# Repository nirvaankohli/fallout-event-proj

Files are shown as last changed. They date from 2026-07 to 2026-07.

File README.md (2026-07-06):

# FALL-E

<replace>with pic of the zine</replace>

---

# The Problem

So the world is ending on the 7th of July, and the human species may not survive. Soup, however, can survive the incoming apocalypse, but only with help. Soup needs a companion to accompany itself(as soup can't walk) to preserve the legacy of humankind for the next species to rule Earth.

---

# What is FALL-E?

FALL-E is a robot inspired by the Pixar movie "WALL-E" and is meant to preserve soup and the legacy of the human species after the destruction of the world. It has a tank-drive chassis with two independent tracks(motor on each side).

FALL-E features a Seeed Studio XIAO ESP32C3, 2 DC Motors, and a DRV8833 Motor Driver. 

---

# Why choose FALL-E?

Our team went into this competition wanting to create something to protect soup and preserve humankind's legacy. We started brainstorming ideas that could do that. Ultimately, two avenues presented themselves: one giving soup weaponry (like a turret) or giving it a form of transportation. We ultimately settled on a robot to keep soup company, provide protection, and a form of transportation. We wanted to base it off of WALL-E because it too was exploring a barren, destroyed Earth.

---

# Zine
 Zine (8)

---

## Bill of materials

- BOM: [bom.csv](bom.csv)

---

# IRL Pics

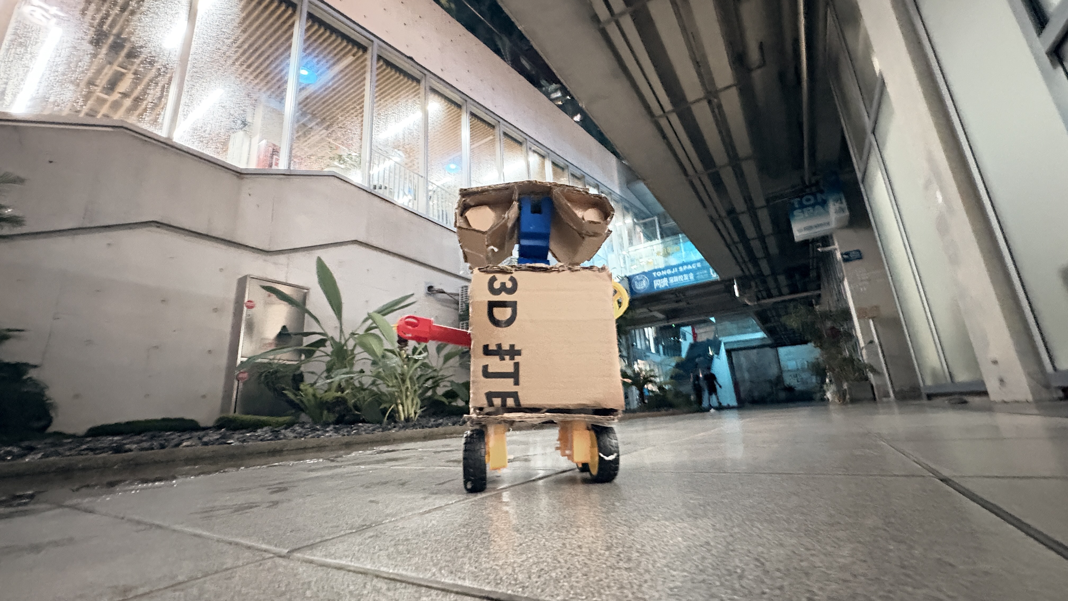
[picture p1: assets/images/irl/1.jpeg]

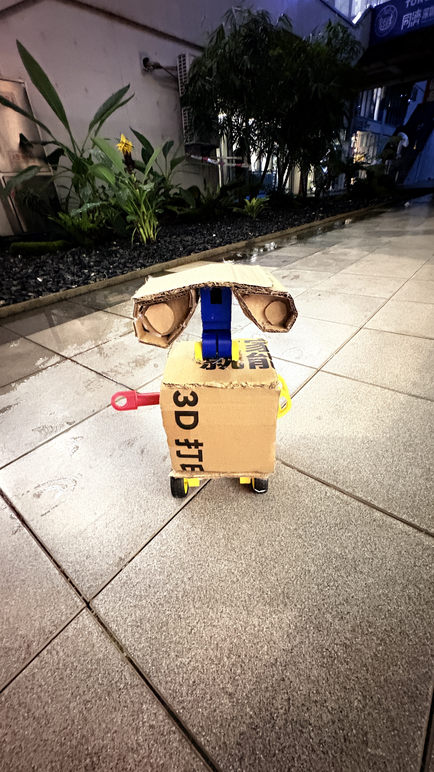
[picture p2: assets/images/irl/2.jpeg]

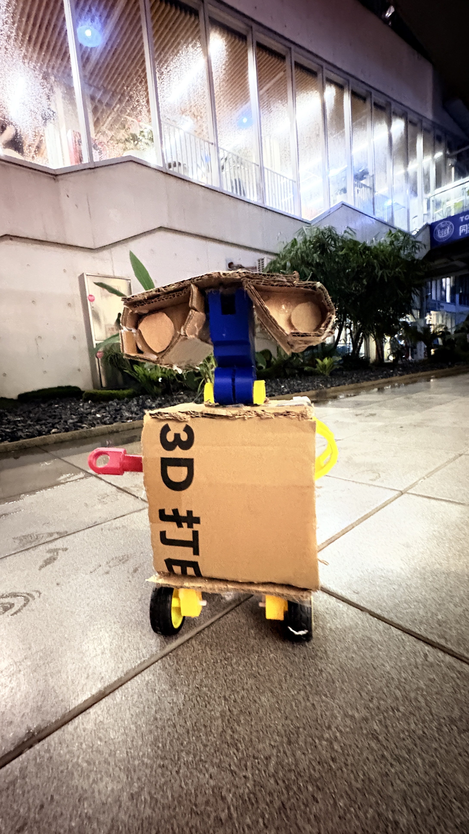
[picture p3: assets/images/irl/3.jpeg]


---

# Schematic/Wiring Diagram

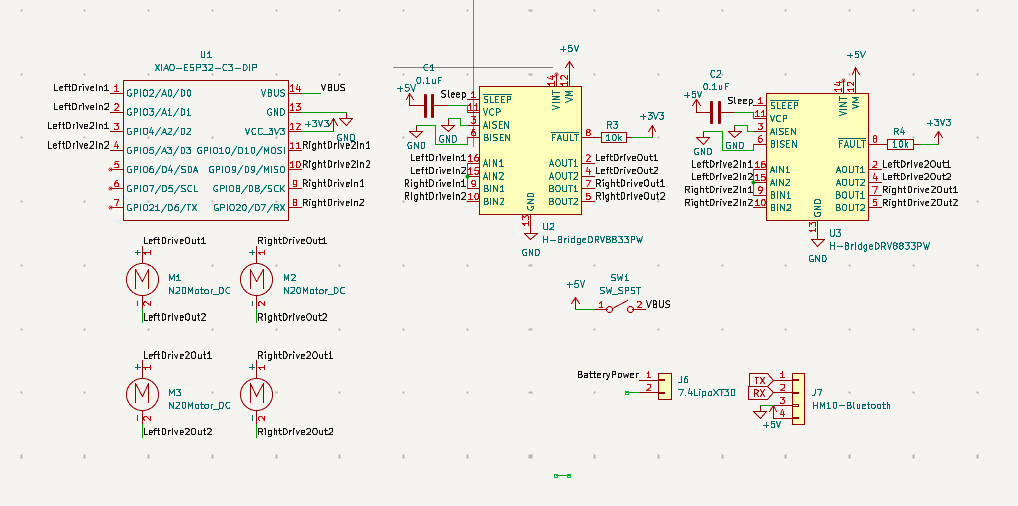
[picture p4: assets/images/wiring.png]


---

# How to assemble it(with pics)?

1. Gather your breadboard, wires, & electronic components.
2. Wire the breadboard following the wiring diagram below:

    a. You need to solder with solder & a soldering iron the microcontroller and it's header pins along with the dupont wires with the tt motors

After you do so, the result should look like this:

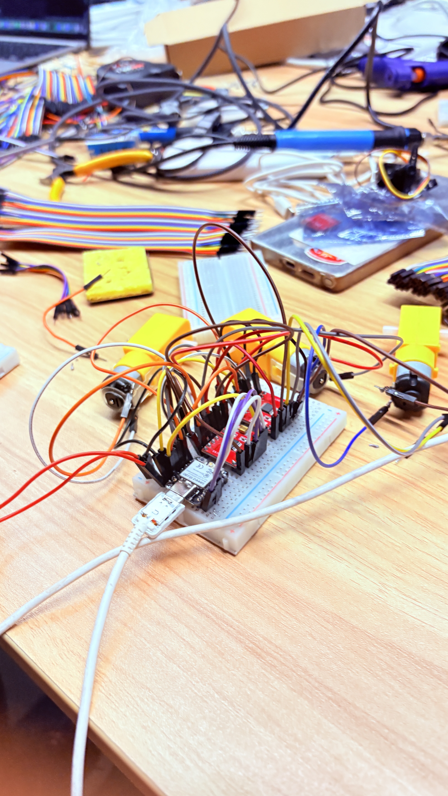
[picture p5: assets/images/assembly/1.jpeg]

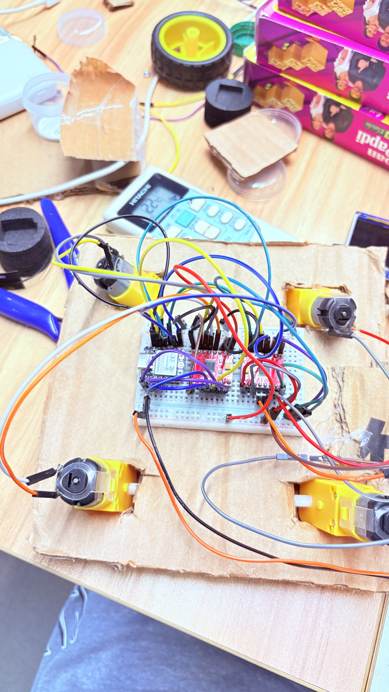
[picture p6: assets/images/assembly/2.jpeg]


3. Next up is too make the body. For the main cube inside cut 6 17x17 cm squares. 
    a. Hot Glue 5 of these squares together to make a cube without a side. 
    b. Cut two rectangular shaoed holes around 3cm away from each other in the middle.
    c. 3D Print `CAD/part2.stl`and from the inside of the cube force it up:

# How to use it?

## Flash XIAO ESP32-C3

1. Plug in the XIAO by USB-C.
2. In `code/esp32code/main.cpp`, set:
   ```cpp
   constexpr char kWifiSsid[] = "YOUR_WIFI";
   constexpr char kWifiPassword[] = "YOUR_PASSWORD";
   ```
3. Build:
   ```bash
   python3 -m platformio run
   ```
4. Flash:
   ```bash
   python3 -m platformio run --target upload --upload-port /dev/cu.usbmodem101
   ```
5. Open serial monitor:
   ```bash
   python3 -m platformio device monitor -b 115200
   ```

## Connect RC

1. Read the IP from serial output.
2. If Wi-Fi fails, connect to `FalloutESP32`.
3. Open `code/esp32code/web_controller.html` in a browser.
4. Connect to:
   ```text
   ws://XIAO_IP:3333/
   ```
   or fallback:
   ```text
   ws://192.168.4.1:3333/
   ```
5. Use the two joysticks to control left/right motors.

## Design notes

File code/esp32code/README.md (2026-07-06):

# XIAO ESP32-C3 Motor Controller

This folder contains the firmware and browser controller for a four-motor tank-drive setup built from two DRV8833 drivers.

- `main.cpp`: XIAO ESP32-C3 firmware with Wi-Fi, WebSocket control, serial test commands, and safety timeout logic.
- `web_controller.html`: Browser UI with two vertical joysticks for left/right tank drive.
- `laptop_echo.py`: Legacy serial/TCP helper from the earlier echo phase. Serial mode still remains useful for quick manual commands, but the main UI is now `web_controller.html`.

## Pin mapping

This firmware fans each left/right drive command out to two motors per side using the bench-tested wiring from the temporary motor-spin sketch:

- `Left front motor IN1` -> `GPIO2`
- `Left front motor IN2` -> `GPIO3`
- `Right front motor IN1` -> `GPIO4`
- `Right front motor IN2` -> `GPIO5`
- `Left rear motor IN1` -> `GPIO20`
- `Left rear motor IN2` -> `GPIO8`
- `Right rear motor IN1` -> `GPIO9`
- `Right rear motor IN2` -> `GPIO10`

Each side is controlled independently:

- Left joystick/command drives both left motors together.
- Right joystick/command drives both right motors together.

DRV8833 drive behavior for each motor channel:

- Forward: `IN1=HIGH`, `IN2=LOW`
- Reverse: `IN1=LOW`, `IN2=HIGH`
- Stop/coast: both inputs `LOW`

Command magnitude still uses `-100..100`, but the current firmware treats any non-zero value as a full-speed direction command.

## Wi-Fi flow

Preferred mode:

1. Set `kWifiSsid` and `kWifiPassword` in [main.cpp](/Users/nirvaank/Code/Hardware/fallout/event/project/fallout-event-proj/code/esp32code/main.cpp).
2. Build and upload the firmware.
3. Read the XIAO IP from the serial monitor.
4. Open `web_controller.html` in a browser and point it at `ws://XIAO_IP:3333/`.

Fallback AP mode:

- SSID: `FalloutESP32`
- Password: none
- XIAO IP: `192.168.4.1`
- WebSocket URL: `ws://192.168.4.1:3333/`

If station Wi-Fi fails, the firmware automatically starts the fallback access point.

## WebSocket command format

Browser clients send JSON messages:

```json
{"type":"drive","left":42,"right":-30}
{"type":"stop"}
{"type":"ping"}
```

The XIAO replies with JSON status or error messages:

```json
{"type":"status","connected":true,"left":42,"right":-30,"reason":"drive"}
{"type":"error","message":"invalid json"}
```

`left` and `right` are normalized to `-100..100`.

## Serial test commands

USB serial still works at `115200` baud and is useful for bench tests:

```text
ping
wifi status
drive 100 100
drive 100 -100
stop
help
```

## Safety stop

- The firmware stops motors by driving all H-bridge inputs `LOW`.
- `SLEEP` is not MCU-controlled in firmware.
- Invalid WebSocket payloads force a safe stop.
- If joystick updates stop arriving for about `300 ms`, all four motors are stopped automatically.
- If the WebSocket client disconnects, all four motors are stopped automatically.

## Startup behavior

- On boot, all four motors spin forward together for about `0.5 s`.
- After that startup check, the firmware stops the motors and starts Wi-Fi/WebSocket control.

## Browser controller

Open [web_controller.html](/Users/nirvaank/Code/Hardware/fallout/event/project/fallout-event-proj/code/esp32code/web_controller.html) in a browser.

- Left pad controls forward and reverse drive.
- Right pad controls turning.
- Up is forward, down is reverse.
- Releasing a joystick returns that motor to zero.
- The page resends the held drive command about every `33 ms` to keep response feeling tight.
- The page shows connection state and the last status reason returned by the XIAO.

## Build and upload

From the repo root:

```bash
python3 -m platformio run
python3 -m platformio run --target upload --upload-port /dev/cu.usbmodem101
python3 -m platformio device monitor -b 115200
```

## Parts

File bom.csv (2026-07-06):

Part Number | Name | Description/Notes | Quantity | Unit Cost (USD) | Line Cost (USD) | Link
2130 | DRV8833 Dual Motor Driver Carrier | Pololu carrier board; one board drives 2 DC motors, so 2 boards cover the 4-motor build | 2 | 10.95 | 21.90 | https://www.pololu.com/product/2130
MT004 | TT Motor + Wheel Kit (4 motors + 4 wheels) | One kit satisfies the 4 TT motors with 4 wheels requirement | 1 | 8.97 | 8.97 | https://www.amazon.com/Motor-Leads-Gearbox-Shaft-200RPM/dp/B0D8H89XDY
B0H6LGM6QB | ELEGOO Dupont Jumper Wire Kit (120 pcs) | Includes male-to-male, male-to-female, and female-to-female jumpers; use the M/M wires as needed | 1 | 6.98 | 6.98 | https://www.amazon.com/ELEGOO-Multicolored-Breadboard-Compatible-Projects/dp/B0H6LGM6QB
113991054 | Seeed Studio XIAO ESP32-C3 | Wi-Fi/BLE MCU board; 1-piece unsoldered option | 1 | 4.90 | 4.90 | https://www.seeedstudio.com/Seeed-XIAO-ESP32C3-p-5431.html
PLA-1KG | ELEGOO PLA Filament 1.75mm 1kg | Representative PLA spool for printing the CAD parts; choose color as needed | 1 | 13.99 | 13.99 | https://us.elegoo.com/products/pla-filament-1-7 5mm-colored-1kg
LBX | Large Moving/Shipping/Packing Box with Handles | Representative large cardboard box | 1 | 2.98 | 2.98 | https://www.homedepot.com/p/The-Home-Depot-Large-Moving-Shipping-Packing-Box-with-Handles-LBX/316324894
PB10PD-SP | Scosche GoBat USB Dual-Port Power Bank 10000mAh | Dual-port power bank; verify the output mix fits your final charging setup | 1 | 44.99 | 44.99 | https://www.staples.com/scosche-gobat-usb-dual-port-power-bank-10000mah-black-pb10pd-sp/product_24562572
A82G2 | Anker USB-A to USB-C Cable (2-pack) | One pack provides the required 2 USB-A to USB-C cables | 1 | 14.99 | 14.99 | https://www.anker.com/products/a82g2
239 | Full Sized Premium Breadboard - 830 Tie Points | Solderless breadboard for prototyping and bring-up | 1 | 5.95 | 5.95 | https://www.adafruit.com/product/239
2230-HD | Scotch Tough Heavy-Duty All-Weather Duct Tape | Representative tape roll for box/chassis assembly and reinforcement | 1 | 10.20 | 10.20 | https://www.homedepot.com/p/3M-Scotch-1-88-in-x-30-yds-Tough-Heavy-Duty-All-Weather-Duct-Tape-2230-HD/205503026
GS25DT | Stanley Dual Temp Glue Sticks (12-pack) | Representative hot glue consumable; requires a compatible glue gun if you do not already have one | 1 | 7.74 | 7.74 | https://www.homedepot.com/p/Stanley-7-16-in-x-10-in-Dual-Temp-Glue-Sticks-12-Pack-GS25DT/204287393
1067268 | Fiskars Everyday 8 in. Non-Stick Titanium Scissors with SoftGrip | General-purpose scissors for cardboard, tape, and trimming work | 1 | 9.99 | 9.99 | https://www.homedepot.com/p/Fiskars-Everyday-8-in-Non-Stick-Titanium-Scissors-with-SoftGrip-1067268/326808934
13276 | AIM 60/40 Tin-Lead Rosin Core Solder Wire 1lb | Electronics solder; use with ventilation/PPE as appropriate | 1 | 28.95 | 28.95 | https://www.amazon.com/AIM-Solder-13276-0-032inch-1lbs-0-81mm-454g/dp/B0B94P31WF
WLIRK3012A | Weller 30W Corded Soldering Iron Kit with LED Halo Ring | Starter soldering iron kit for electronics and wiring work | 1 | 20.56 | 20.56 | https://www.homedepot.com/p/Weller-30-Watt-120-Volt-Corded-Soldering-Iron-Kit-with-LED-Halo-Ring-WLIRK3012A/315743439

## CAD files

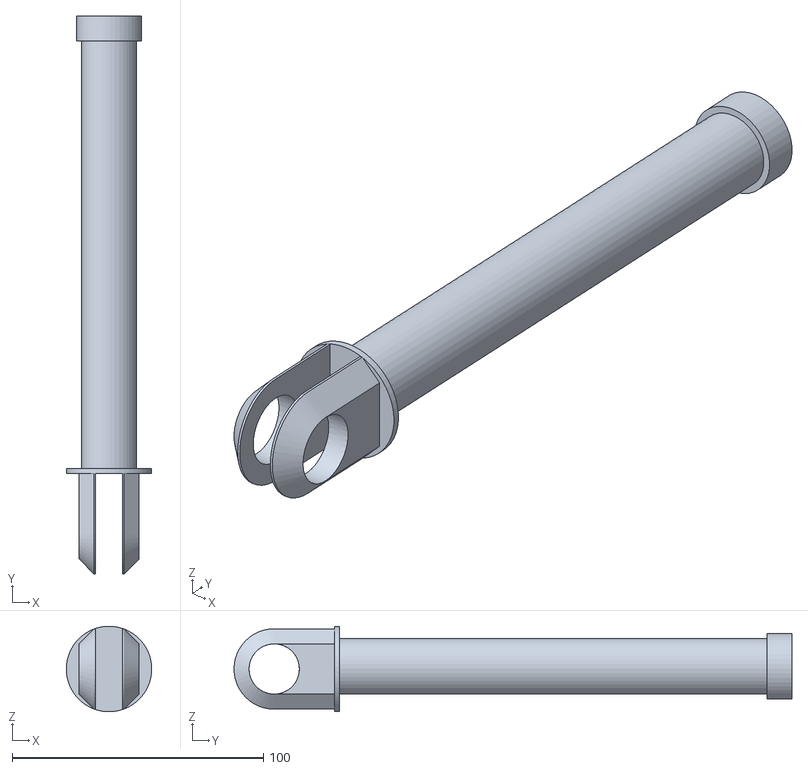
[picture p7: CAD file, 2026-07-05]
CAD/Hand5.stl
34.0 x 222.0 x 34.0

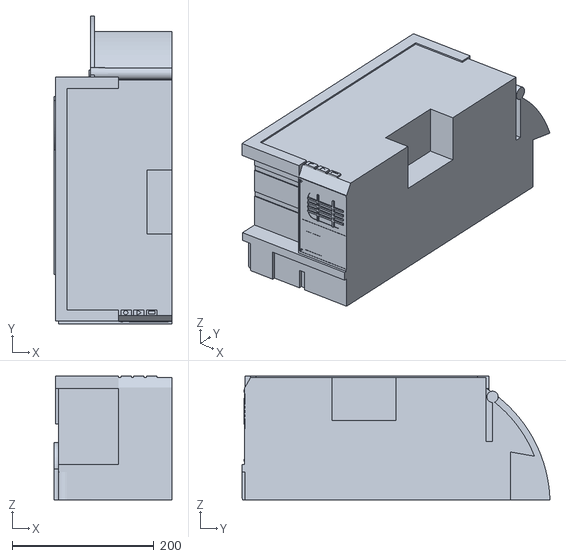
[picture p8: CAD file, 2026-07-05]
CAD/BodyTopleft.stl
166.0 x 433.9 x 174.0

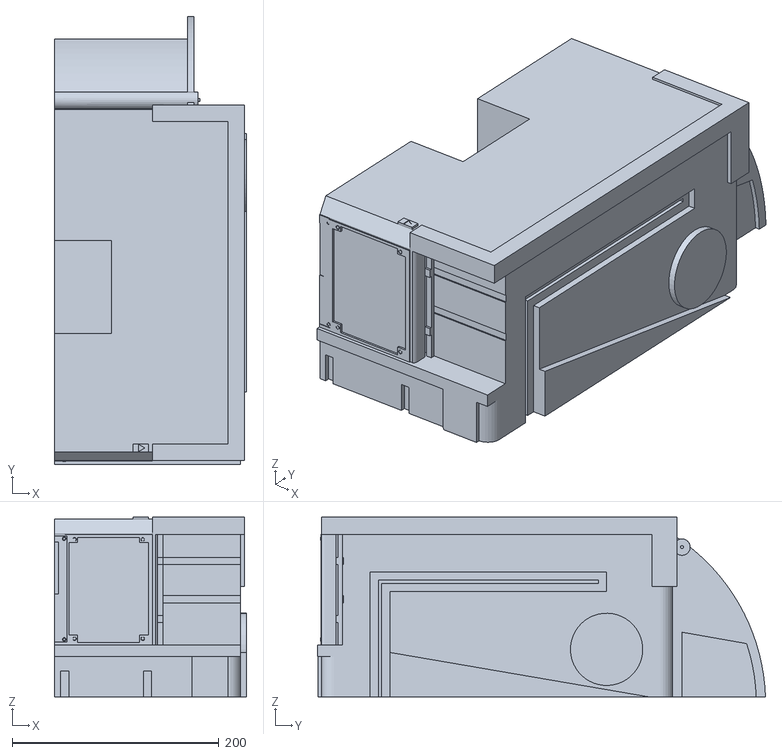
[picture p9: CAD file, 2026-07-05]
CAD/BodyTopRight.stl
186.0 x 433.9 x 174.0

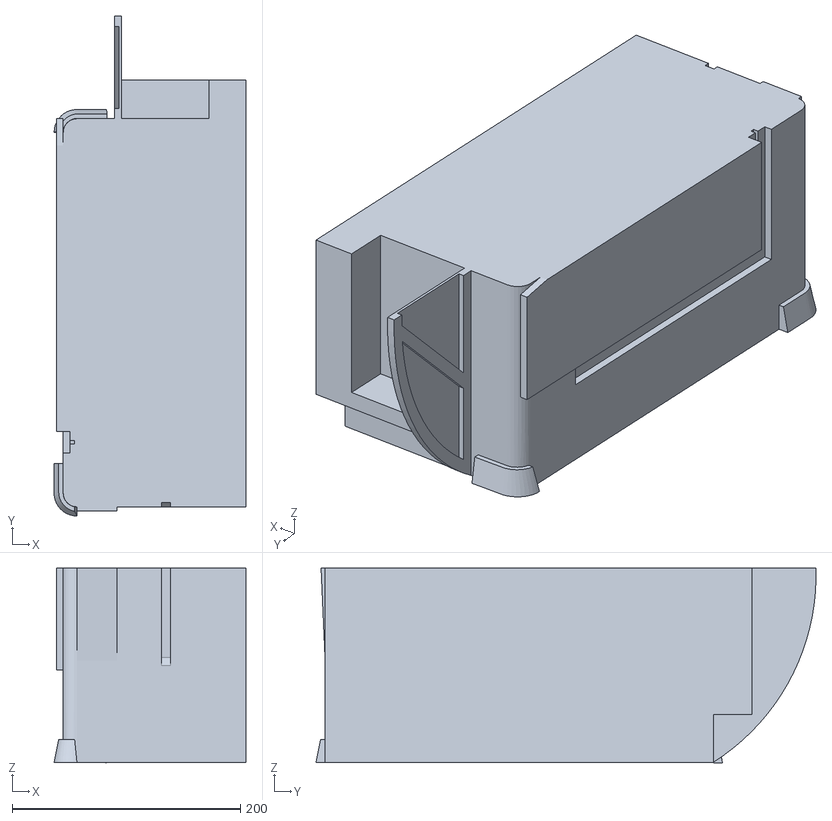
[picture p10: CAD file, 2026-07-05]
CAD/BodyBottomLeft.stl
168.0 x 438.0 x 170.4

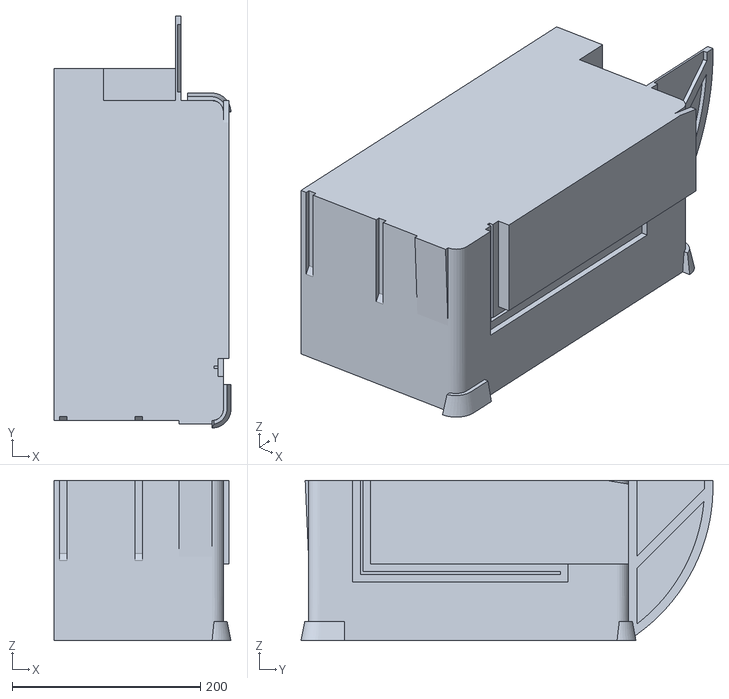
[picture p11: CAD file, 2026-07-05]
CAD/BodyBottomRight.stl
188.0 x 438.0 x 170.4

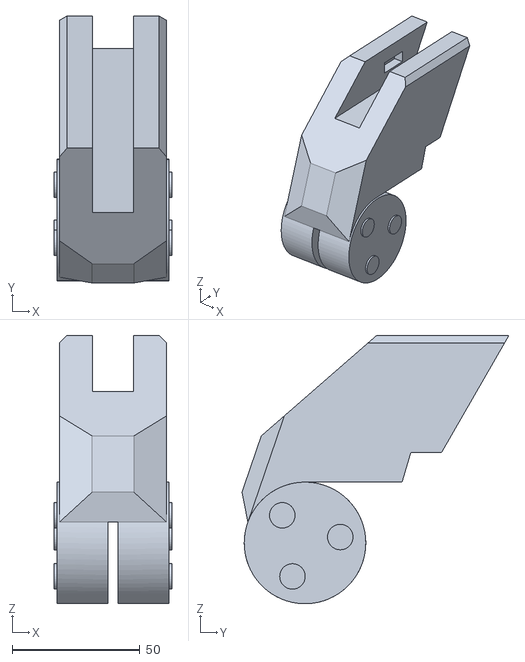
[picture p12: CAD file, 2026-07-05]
CAD/Face4.stl
46.0 x 104.5 x 105.1

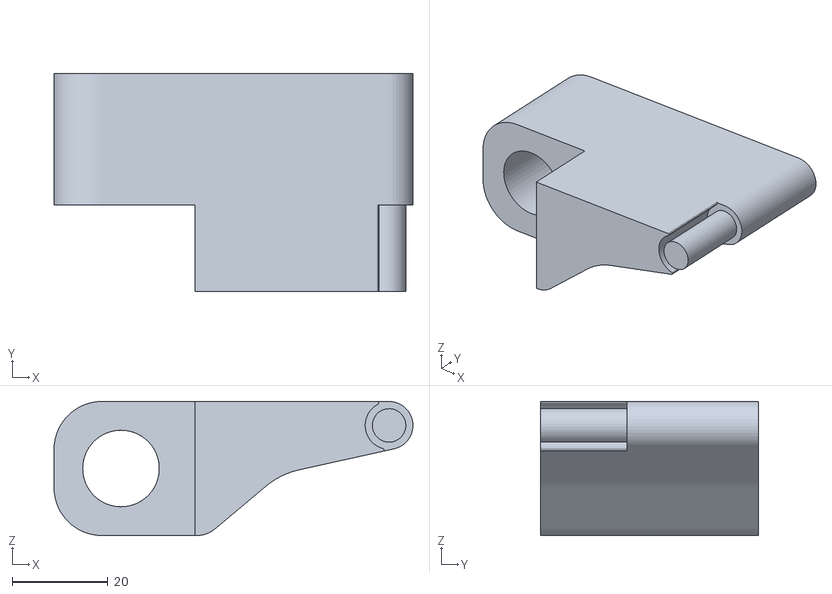
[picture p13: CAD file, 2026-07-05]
CAD/Fingers 1,2.stl
75.0 x 45.5 x 28.0

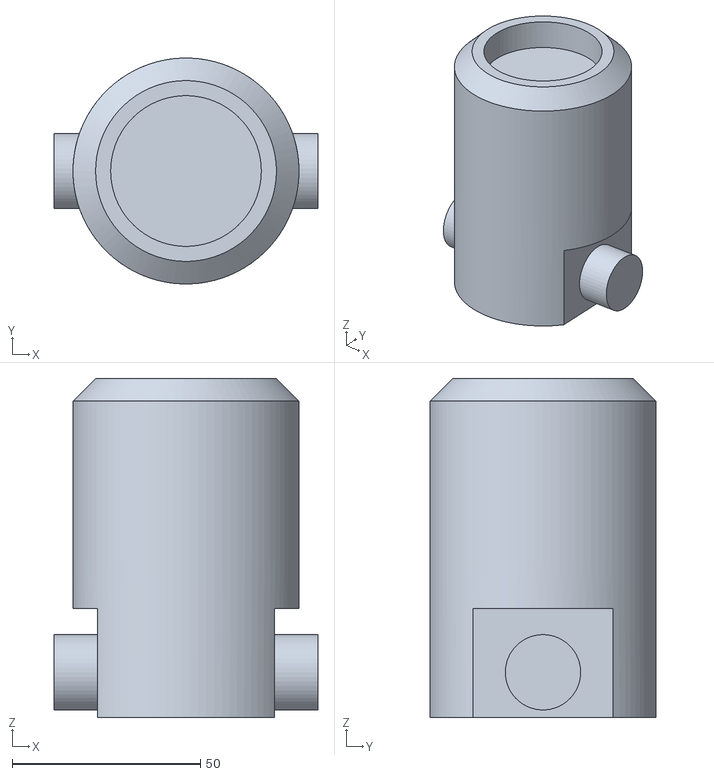
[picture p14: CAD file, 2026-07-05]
CAD/part3.stl
70.0 x 60.0 x 90.0

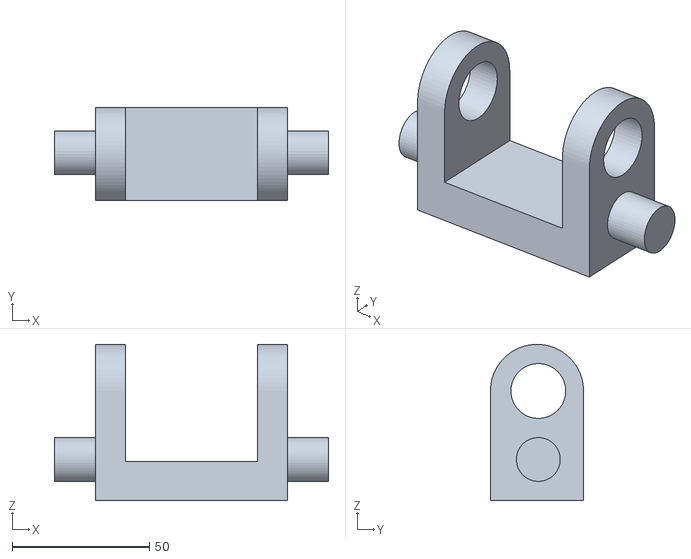
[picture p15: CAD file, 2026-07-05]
CAD/part2.stl
100.0 x 34.0 x 57.0

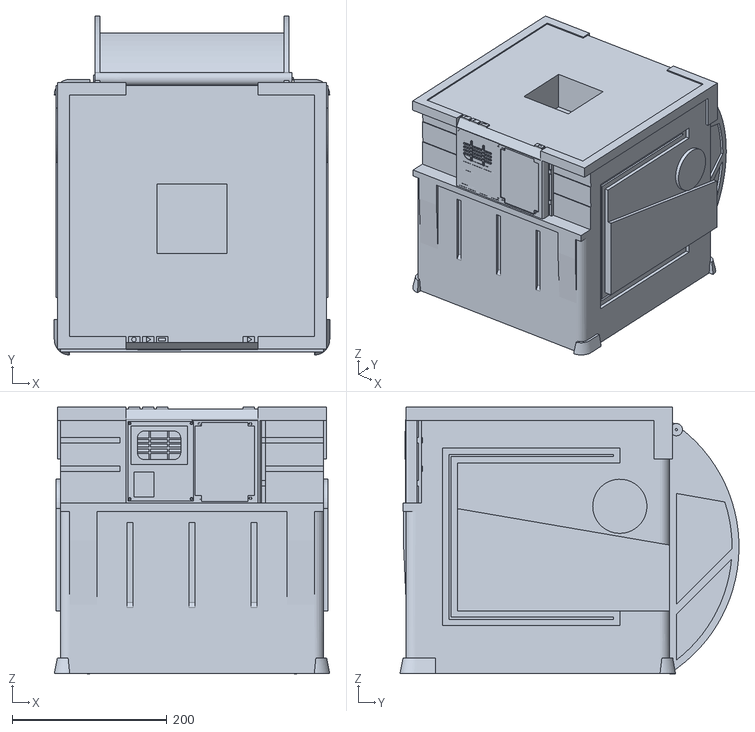
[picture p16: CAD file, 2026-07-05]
CAD/bodywalle.stl
356.0 x 438.0 x 344.4

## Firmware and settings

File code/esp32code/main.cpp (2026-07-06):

#include <Arduino.h>
#include <ArduinoJson.h>
#include <WiFi.h>
#include <WebSocketsServer.h>

namespace {

constexpr uint32_t kBaudRate = 115200;
constexpr uint16_t kWebSocketPort = 3333;
constexpr uint32_t kCommandTimeoutMs = 300;
constexpr int kCommandDeadzone = 8;
constexpr int kBootMotorSpinCommand = 100;
constexpr uint32_t kBootMotorSpinMs = 500;
constexpr char kWifiSsid[] = "Nirvaan's Phone";
constexpr char kWifiPassword[] = "himynameisnirvaan";
constexpr char kFallbackAccessPointSsid[] = "FalloutESP32";
constexpr uint8_t kFallbackAccessPointChannel = 6;
constexpr uint8_t kActivityLedPin = 255;
constexpr uint8_t kSleepPin = 255;

struct MotorPins {
  uint8_t in1Pin;
  uint8_t in2Pin;
  bool invertDirection;
};

// These pin pairs match the temporary bench-test sketch that already spun all four motors.
constexpr MotorPins kLeftMotors[] = {
    {2, 3, false},
    {4, 5, true},
};

constexpr MotorPins kRightMotors[] = {
    {20, 8, false},
    {9, 10, true},
};

IPAddress kFallbackAccessPointIp(192, 168, 4, 1);
IPAddress kFallbackAccessPointGateway(192, 168, 4, 1);
IPAddress kFallbackAccessPointSubnet(255, 255, 255, 0);

WebSocketsServer webSocketServer(kWebSocketPort);
bool wifiReady = false;
bool timeoutStopReported = false;
uint8_t activeClientCount = 0;

struct MotorState {
  int left = 0;
  int right = 0;
  uint32_t lastCommandAtMs = 0;
} motorState;

String readLineFrom(Stream &stream) {
  static String buffer;

  while (stream.available() > 0) {
    const char nextChar = static_cast<char>(stream.read());

    if (nextChar == '\r') {
      continue;
    }

    if (nextChar == '\n') {
      const String line = buffer;
      buffer = "";
      return line;
    }

    buffer += nextChar;
  }

  return "";
}

int clampCommand(int value) {
  return constrain(value, -100, 100);
}

int normalizeCommand(int value) {
  const int clamped = clampCommand(value);
  return abs(clamped) <= kCommandDeadzone ? 0 : clamped;
}

void setDriverSleep(bool enabled) {
  if (kSleepPin == 255) {
    return;
  }

  digitalWrite(kSleepPin, enabled ? HIGH : LOW);
}

void setActivityLed(bool enabled) {
  if (kActivityLedPin == 255) {
    return;
  }

  digitalWrite(kActivityLedPin, enabled ? HIGH : LOW);
}

void stopMotorPins(uint8_t in1Pin, uint8_t in2Pin) {
  digitalWrite(in1Pin, LOW);
  digitalWrite(in2Pin, LOW);
}

void applyMotorPins(uint8_t in1Pin, uint8_t in2Pin, int command) {
  if (command > 0) {
    digitalWrite(in1Pin, HIGH);
    digitalWrite(in2Pin, LOW);
    return;
  }

  if (command < 0) {
    digitalWrite(in1Pin, LOW);
    digitalWrite(in2Pin, HIGH);
    return;
  }

  stopMotorPins(in1Pin, in2Pin);
}

void stopMotor(const MotorPins &motor) {
  stopMotorPins(motor.in1Pin, motor.in2Pin);
}

void applyMotor(const MotorPins &motor, int command) {
  const int adjustedCommand = motor.invertDirection ? -command : command;
  applyMotorPins(motor.in1Pin, motor.in2Pin, adjustedCommand);
}

template <size_t N>
void applyMotorBank(const MotorPins (&motors)[N], int command) {
  for (const MotorPins &motor : motors) {
    applyMotor(motor, command);
  }
}

void applyLeftMotors(int command) {
  applyMotorBank(kLeftMotors, command);
}

void applyRightMotors(int command) {
  applyMotorBank(kRightMotors, command);
}

String buildStatusJson(const char *reason = nullptr) {
  JsonDocument response;
  response["type"] = "status";
  response["connected"] = activeClientCount > 0;
  response["left"] = motorState.left;
  response["right"] = motorState.right;
  if (reason != nullptr) {
    response["reason"] = reason;
  }

  String message;
  serializeJson(response, message);
  return message;
}

String buildErrorJson(const char *messageText) {
  JsonDocument response;
  response["type"] = "error";
  response["message"] = messageText;

  String message;
  serializeJson(response, message);
  return message;
}

void broadcastStatus(const char *reason = nullptr) {
  String message = buildStatusJson(reason);
  webSocketServer.broadcastTXT(message);
}

void sendStatusToClient(uint8_t clientNumber, const char *reason = nullptr) {
  String message = buildStatusJson(reason);
  webSocketServer.sendTXT(clientNumber, message);
}

void sendErrorToClient(uint8_t clientNumber, const char *messageText) {
  String message = buildErrorJson(messageText);
  webSocketServer.sendTXT(clientNumber, message);
}

void stopAllMotors(const char *reason) {
  motorState.left = 0;
  motorState.right = 0;
  applyLeftMotors(0);
  applyRightMotors(0);
  setDriverSleep(false);
  setActivityLed(false);
  timeoutStopReported = false;
  Serial.printf("[motor] stop reason=%s\n", reason);
}

void applyDriveCommand(int left, int right, const char *source) {
  motorState.left = normalizeCommand(left);
  motorState.right = normalizeCommand(right);
  motorState.lastCommandAtMs = millis();
  timeoutStopReported = false;

  const bool anyMotorActive = motorState.left != 0 || motorState.right != 0;
  setDriverSleep(anyMotorActive);
  setActivityLed(anyMotorActive);
  applyLeftMotors(motorState.left);
  applyRightMotors(motorState.right);

  Serial.printf("[motor] %s left=%d right=%d sleep=%s\n",
                source,
                motorState.left,
                motorState.right,
                anyMotorActive ? "HIGH" : "LOW");
}

template <size_t N>
void configureMotorBank(const MotorPins (&motors)[N]) {
  for (const MotorPins &motor : motors) {
    pinMode(motor.in1Pin, OUTPUT);
    pinMode(motor.in2Pin, OUTPUT);
    stopMotor(motor);
  }
}

void configureMotorPins() {
  configureMotorBank(kLeftMotors);
  configureMotorBank(kRightMotors);

  if (kActivityLedPin != 255) {
    pinMode(kActivityLedPin, OUTPUT);
    digitalWrite(kActivityLedPin, LOW);
  }

  if (kSleepPin != 255) {
    pinMode(kSleepPin, OUTPUT);
    digitalWrite(kSleepPin, LOW);
  }

  motorState.left = 0;
  motorState.right = 0;
  motorState.lastCommandAtMs = 0;
  timeoutStopReported = false;
}

void runBootMotorTest() {
  Serial.println("[boot] Running startup motor spin");
  applyDriveCommand(kBootMotorSpinCommand, kBootMotorSpinCommand, "boot-spin");
  delay(kBootMotorSpinMs);
  stopAllMotors("boot-spin-complete");
  Serial.println("[boot] Startup motor spin complete");
}

void printHelp(Stream &stream) {
  stream.println("Commands:");
  stream.println("  ping");
  stream.println("  wifi status");
  stream.println("  drive <left:-100..100> <right:-100..100>");
  stream.println("  stop");
  stream.println("  help");
}

void reportWifiStatus(Stream &stream, const char *channelName) {
  if (!wifiReady) {
    stream.printf("[%s] wifi not ready\n", channelName);
    return;
  }

  if (WiFi.getMode() == WIFI_STA && WiFi.status() == WL_CONNECTED) {
    stream.printf("[%s] wifi station ssid=%s ip=%s ws_port=%u\n",
                  channelName,
                  WiFi.SSID().c_str(),
                  WiFi.localIP().toString().c_str(),
                  kWebSocketPort);
    return;
  }

  stream.printf("[%s] wifi ap ssid=%s ip=%s ws_port=%u\n",
                channelName,
                kFallbackAccessPointSsid,
                WiFi.softAPIP().toString().c_str(),
                kWebSocketPort);
}

bool parseDriveLine(const String &message, int &left, int &right) {
  if (!message.startsWith("drive ")) {
    return false;
  }

  const int parsedCount = sscanf(message.c_str(), "drive %d %d", &left, &right);
  return parsedCount == 2;
}

void handleSerialMessage(const String &message, Stream &replyStream, const char *channelName) {
  if (message.isEmpty()) {
    return;
  }

  if (message == "ping") {
    replyStream.printf("[%s] pong\n", channelName);
    return;
  }

  if (message == "wifi status") {
    reportWifiStatus(replyStream, channelName);
    return;
  }

  if (message == "help") {
    printHelp(replyStream);
    return;
  }

  if (message == "stop") {
    stopAllMotors("serial stop");
    replyStream.printf("[%s] %s\n", channelName, buildStatusJson("serial-stop").c_str());
    broadcastStatus("serial-stop");
    return;
  }

  int left = 0;
  int right = 0;
  if (parseDriveLine(message, left, right)) {
    applyDriveCommand(left, right, "serial");
    replyStream.printf("[%s] %s\n", channelName, buildStatusJson("serial-drive").c_str());
    broadcastStatus("serial-drive");
    return;
  }

  stopAllMotors("serial invalid");
  replyStream.printf("[%s] %s\n", channelName, buildErrorJson("invalid serial command").c_str());
  broadcastStatus("invalid-command");
}

void startWebSocketServer() {
  webSocketServer.begin();
  webSocketServer.enableHeartbeat(30000, 10000, 2);
  Serial.printf("[boot] WebSocket server listening on port %u\n", kWebSocketPort);
}

void startWifiAccessPoint() {
  WiFi.mode(WIFI_AP);
  WiFi.setSleep(false);
  const bool configOk =
      WiFi.softAPConfig(kFallbackAccessPointIp, kFallbackAccessPointGateway, kFallbackAccessPointSubnet);
  const bool started = WiFi.softAP(kFallbackAccessPointSsid, nullptr, kFallbackAccessPointChannel, 0, 2);
  if (!configOk) {
    Serial.println("[boot] Failed to configure Wi-Fi access point IP.");
  }
  if (!started) {
    Serial.println("[boot] Failed to start Wi-Fi access point.");
    return;
  }

  wifiReady = true;
  startWebSocketServer();

  Serial.printf("[boot] Fallback Wi-Fi AP ready. SSID=%s security=open channel=%u\n",
                kFallbackAccessPointSsid,
                kFallbackAccessPointChannel);
  Serial.printf("[boot] Open WebSocket ws://%s:%u/\n",
                WiFi.softAPIP().toString().c_str(),
                kWebSocketPort);
}

void startWifiStation() {
  if (strlen(kWifiSsid) == 0) {
    Serial.println("[boot] No station Wi-Fi credentials configured.");
    startWifiAccessPoint();
    return;
  }

  WiFi.mode(WIFI_STA);
  WiFi.setSleep(false);
  WiFi.begin(kWifiSsid, kWifiPassword);

  Serial.printf("[boot] Connecting to Wi-Fi SSID=%s\n", kWifiSsid);

  const uint32_t connectStart = millis();
  while (WiFi.status() != WL_CONNECTED && millis() - connectStart < 15000) {
    delay(250);
    Serial.print(".");
  }
  Serial.println();

  if (WiFi.status() != WL_CONNECTED) {
    Serial.println("[boot] Station Wi-Fi connect failed. Starting fallback AP instead.");
    startWifiAccessPoint();
    return;
  }

  wifiReady = true;
  startWebSocketServer();

  Serial.printf("[boot] Wi-Fi station connected. SSID=%s ip=%s ws_port=%u\n",
                kWifiSsid,
                WiFi.localIP().toString().c_str(),
                kWebSocketPort);
}

bool handleWebSocketJson(const String &message, uint8_t clientNumber) {
  JsonDocument payload;
  const DeserializationError error = deserializeJson(payload, message);
  if (error) {
    sendErrorToClient(clientNumber, "invalid json");
    stopAllMotors("invalid json");
    broadcastStatus("invalid-json");
    return false;
  }

  const char *type = payload["type"];
  if (type == nullptr) {
    sendErrorToClient(clientNumber, "missing type");
    stopAllMotors("missing type");
    broadcastStatus("invalid-command");
    return false;
  }

  if (strcmp(type, "drive") == 0) {
    if (!payload["left"].is<int>() || !payload["right"].is<int>()) {
      sendErrorToClient(clientNumber, "drive requires integer left/right");
      stopAllMotors("invalid drive payload");
      broadcastStatus("invalid-drive");
      return false;
    }

    applyDriveCommand(payload["left"].as<int>(), payload["right"].as<int>(), "websocket");
    broadcastStatus("drive");
    return true;
  }

  if (strcmp(type, "stop") == 0) {
    stopAllMotors("websocket stop");
    broadcastStatus("stop");
    return true;
  }

  if (strcmp(type, "ping") == 0) {
    sendStatusToClient(clientNumber, "pong");
    return true;
  }

  sendErrorToClient(clientNumber, "unknown command type");
  stopAllMotors("unknown command");
  broadcastStatus("invalid-command");
  return false;
}

void handleWebSocketEvent(uint8_t clientNumber, WStype_t type, uint8_t *payload, size_t length) {
  switch (type) {
    case WStype_CONNECTED: {
      activeClientCount++;
      IPAddress ip = webSocketServer.remoteIP(clientNumber);
      Serial.printf("[wifi] websocket client %u connected from %s active=%u\n",
                    clientNumber,
                    ip.toString().c_str(),
                    activeClientCount);
      sendStatusToClient(clientNumber, "connected");
      break;
    }

    case WStype_DISCONNECTED: {
      if (activeClientCount > 0) {
        activeClientCount--;
      }
      Serial.printf("[wifi] websocket client %u disconnected active=%u\n", clientNumber, activeClientCount);
      stopAllMotors("client disconnected");
      broadcastStatus("client-disconnected");
      break;
    }

    case WStype_TEXT: {
      String message;
      message.reserve(length);
      for (size_t index = 0; index < length; ++index) {
        message += static_cast<char>(payload[index]);
      }
      message.trim();
      Serial.printf("[wifi] rx client=%u payload=%s\n", clientNumber, message.c_str());
      handleWebSocketJson(message, clientNumber);
      break;
    }

    default:
      break;
  }
}

void maintainSafetyTimeout() {
  const bool anyMotorActive = motorState.left != 0 || motorState.right != 0;
  if (!anyMotorActive) {
    return;
  }

  if (millis() - motorState.lastCommandAtMs <= kCommandTimeoutMs) {
    return;
  }

  stopAllMotors("command timeout");
  if (!timeoutStopReported) {
    broadcastStatus("timeout");
    timeoutStopReported = true;
  }
}

}  // namespace

void setup() {
  configureMotorPins();
  Serial.begin(kBaudRate);

  const uint32_t serialWaitStart = millis();
  while (!Serial && millis() - serialWaitStart < 3000) {
    delay(10);
  }

  Serial.println();
  Serial.println("[boot] XIAO ESP32-C3 motor controller starting");
  Serial.printf("[boot] USB serial ready at %lu baud\n", static_cast<unsigned long>(kBaudRate));

  stopAllMotors("boot");
  runBootMotorTest();
  printHelp(Serial);
  startWifiStation();
  webSocketServer.onEvent(handleWebSocketEvent);
}

void loop() {
  const String serialMessage = readLineFrom(Serial);
  if (serialMessage.length() > 0) {
    handleSerialMessage(serialMessage, Serial, "usb");
  }

  if (wifiReady) {
    webSocketServer.loop();
  }

  maintainSafetyTimeout();
}

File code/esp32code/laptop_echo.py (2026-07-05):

#!/usr/bin/env python3

from __future__ import annotations

import argparse
import glob
import socket
import sys
import time

def auto_detect_serial_port() -> str:
    candidates = sorted(
        glob.glob("/dev/cu.usbmodem*")
        + glob.glob("/dev/cu.SLAB_USBtoUART*")
        + glob.glob("/dev/cu.wchusbserial*")
    )
    if not candidates:
        raise SystemExit("No likely ESP32 serial device found. Pass --port explicitly.")
    return candidates[0]


def open_serial_client(port: str, baud: int):
    try:
        import serial
    except ImportError as exc:  # pragma: no cover - user environment dependent
        raise SystemExit(
            "pyserial is required for serial mode. Install it with: python3 -m pip install pyserial"
        ) from exc

    device = serial.Serial(port=port, baudrate=baud, timeout=1)
    time.sleep(2)
    device.reset_input_buffer()
    return device


def run_serial_mode(port: str | None, baud: int) -> int:
    resolved_port = port or auto_detect_serial_port()
    print(f"Opening serial connection on {resolved_port} at {baud} baud")
    device = open_serial_client(resolved_port, baud)
    print("Type text and press Enter. Ctrl+C to quit.")
    print("Try: ping")

    try:
        while True:
            outgoing = input("> ").strip()
            if not outgoing:
                continue

            device.write((outgoing + "\n").encode("utf-8"))
            device.flush()

            incoming = device.readline().decode("utf-8", errors="replace").strip()
            if incoming:
                print(f"ESP32: {incoming}")
            else:
                print("ESP32: no response before timeout")
    except KeyboardInterrupt:
        print("\nClosing serial connection")
        return 0
    finally:
        device.close()


def run_tcp_mode(host: str, port: int) -> int:
    print(f"Opening TCP connection to {host}:{port}")
    try:
        with socket.create_connection((host, port), timeout=5) as sock:
            reader = sock.makefile("r", encoding="utf-8", newline="\n")
            print("Type text and press Enter. Ctrl+C to quit.")
            try:
                while True:
                    outgoing = input("> ").strip()
                    if not outgoing:
                        continue

                    sock.sendall((outgoing + "\n").encode("utf-8"))
                    incoming = reader.readline().strip()
                    if incoming:
                        print(f"ESP32: {incoming}")
                    else:
                        print("ESP32: connection closed")
                        return 1
            except KeyboardInterrupt:
                print("\nClosing TCP connection")
                return 0
    except OSError as exc:
        if exc.errno == 51:
            print("Network is unreachable.")
            print("Join the ESP32 Wi-Fi network 'Fallout-ESP32-Echo' first, then retry.")
            print(f"After joining, connect again to {host}:{port}.")
            return 2

        raise


def parse_args() -> argparse.Namespace:
    parser = argparse.ArgumentParser(description=__doc__)
    parser.add_argument(
        "--mode",
        choices=("serial", "tcp"),
        default="serial",
        help="Communication mode to use.",
    )
    parser.add_argument(
        "--port",
        help="Serial device path for --mode serial, like /dev/cu.usbmodem101.",
    )
    parser.add_argument(
        "--baud",
        type=int,
        default=115200,
        help="Serial baud rate.",
    )
    parser.add_argument(
        "--host",
        default="192.168.4.1",
        help="ESP32 IP address for --mode tcp.",
    )
    parser.add_argument(
        "--tcp-port",
        type=int,
        default=3333,
        help="ESP32 TCP port for --mode tcp.",
    )
    return parser.parse_args()


def main() -> int:
    args = parse_args()

    if args.mode == "serial":
        return run_serial_mode(args.port, args.baud)

    return run_tcp_mode(args.host, args.tcp_port)


if __name__ == "__main__":
    sys.exit(main())

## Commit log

2026-07-04 Tsomeone else add it
    [fallout-wiring.kicad_pcb, fallout-wiring.kicad_sch]
2026-07-04 updated schematic
    [OnGod.kicad_sch]
2026-07-05 Add ESP32 echo bridge and laptop client
2026-07-05 Ignore ESP32 helper Python cache files
2026-07-05 Add ESP32 Wi-Fi access point echo mode
2026-07-05 Save current project changes
2026-07-05 Add XIAO Wi-Fi motor controller
2026-07-05 finger 1,2
    [Fingers 1,2.stl]
2026-07-05 fac3 4
    [Face4.stl]
2026-07-05 split body
    [BodyBottomLeft.stl, BodyBottomRight.stl, BodyTopRight.stl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]
2026-07-06 test code to see if wiring is correct
    [main.cpp]
